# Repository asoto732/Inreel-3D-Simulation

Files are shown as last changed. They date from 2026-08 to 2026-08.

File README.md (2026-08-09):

# InReel Deflection System — 3D Model / CAD

Mechanical CAD for the deflection (gimbal) system on Sandvik's electrified rotary drill rigs. Companion repo to the firmware/control-logic repo (`Sandvik-Common/dri`), split out because CAD assets (STEP/STL exports) don't belong version-controlled alongside code.

## Scope

Two-axis gimbal that measures cable angle deviation and feeds the cable reel control loop. This repo covers the mechanical yoke/mounting design; encoder signal processing and control logic live in `dri`.

## Current encoder — TURCK QR24

| Parameter | Value |
|---|---|
| Model | RI360P0-QR24M0-CNX4-2H1150 (TURCK ID 1590914) |
| Measuring principle | Contactless, inductive (RLC coupling) |
| Shaft diameter | **12 mm** — encoder mounts directly, no stub/adapter needed |
| Air gap | Sensor head and positioning element are separate; nominal **1.5 mm** gap between them |
| Mounting | Hollow shaft 6–20 mm; separate P-series positioning element (per axis) + aluminum ring; mounting aid MT-QR24, closure cap VZ 3 |
| Sealing | IP68 / IP69K |

Full datasheet: `edb_1590914_eng_us.pdf` (see `dri` repo's `CLAUDE.md` for the reference table).

## Real yoke/frame CAD (added 2026-07-23)

`cad/` holds the real, externally-authored gimbal parts (not generated by anything in this repo) — a proper 2-axis design:

| File | Part | Native size (in) |
|---|---|---|
| `mounting_frame.stl` | Base frame, bolts to the rig, carries the axis-0 bearing bosses | 17.3 × 21.4 × 20.8 |
| `outer_yoke.stl` | Rectangular yoke ring — bosses on one side pair bolt to the frame (axis-0), the perpendicular pair carries the inner yoke (axis-1). **Replaced 2026-08-09** — see below. | 16.5 × 20.9 × 3.8 |
| `inner_yoke.stl` | Tube holding the encoder/cable passthrough, with two stub pivot shafts for the outer yoke's axis-1 bosses. **Replaced 2026-08-09** — see below. | 15.9 × 6.1 × 12.0 |

These are wired into `docs/gimbal_axis_simulator.html` (loaded live via `STLLoader`, not embedded — at ~1.8–4.7MB each, base64-embedding like the encoder experiment would have bloated the HTML past being readable/diffable, so the simulator now needs to be served rather than double-clicked; see below). The procedural placeholder frame/rings remain as a fallback if a load fails.

**Pivot alignment (axis-0, frame ↔ outer yoke): confirmed with exact CAD coordinates**, not mesh-forensics estimates. An early mesh-proximity heuristic found frame "already touching" outer_yoke in the raw STL export and assumed that meant they shared a coordinate system — that assumption was wrong (a direct proximity check later showed frame was actually closer, in the raw export, to a *different* boss pair than the one that's really meant to mate, confirmed against reference photos). The user then read exact hole/pin center coordinates directly from the CAD tool:

| Feature | Native coordinates (in) |
|---|---|
| Outer yoke, left shaft-hole | (7.1061, -2.2958, 1.5000) |
| Outer yoke, right shaft-hole | (7.1061, 17.1822, 1.5000) |
| Frame, left leg-hole | (3.3266, -5.7665, -14.1875) |
| Frame, right leg-hole | (3.3266, 13.2085, -14.1875) |

Both pairs run along native Y (consistent axis direction, good sign the parts are meant to mate here). `FRAME_NATIVE_OFFSET` in `transformYokeGeometry()` translates frame's leg-hole axis onto outer yoke's shaft-hole axis exactly on the two perpendicular axes; the third (axial) direction has the two pairs' hole-spacing differing by ~0.5in, so a single rigid transform can't satisfy both endpoints exactly — the residual (~6.4mm) is split evenly between the two ends, verified directly against the transform math (not just the mesh) in-browser.

**Pivot alignment (axis-1, outer yoke ↔ inner yoke): also confirmed with exact CAD coordinates.**

| Feature | Native coordinates (in) |
|---|---|
| Outer yoke, left female pivot hole | (13.1061, 7.4432, 1.5000) |
| Outer yoke, right female pivot hole | (1.1061, 7.4432, 1.5000) |
| Inner yoke, left male stub shaft | (3.0700, -8.1604, 10.7500) |
| Inner yoke, right male stub shaft | (18.4697, -8.1604, 10.7500) |

Both pairs run along native X. Nice cross-check: this pair's midpoint X (7.1061) and fixed Y (7.4432) both match axis-0's numbers exactly, confirming both axes truly intersect at one consistent point, `NATIVE_PIVOT = {x:7.1061, y:7.4432, z:1.5000}` (fully exact now, not an estimate on any axis).

Unlike axis-0, this pair has a much bigger span mismatch: inner yoke's stub-to-stub span is 15.40in, outer yoke's hole-to-hole span is 12.00in — a 3.40in difference. Midpoint-aligning (same method as axis-0) leaves a real **~1.7in (~43mm) residual per end**, confirmed directly against the live transform math via `javascript_tool`, not just the mesh. Checked whether this was a left/right mislabeling (it isn't — neither direct nor crossed point correspondence explains it away) — more likely a shaft's own "center" (a point along its length) isn't the same reference as a hole's center once it's inserted partway. Flagged rather than silently absorbed; if this matters for anything beyond visualization, worth asking whichever coordinates were pulled whether the shaft's *insertion-end* point (rather than its overall midpoint) was intended.

**Frame orientation (up/down flip, then 90° yaw) — visually confirmed correct by the user**, but the yaw fix (`rotateY90`) was later found to be a real bug — see below.

**Which slider drives which rotation.** Briefly swapped (X/Y ↔ innerGroup/outerGroup), then reverted ("the axes are not correct") — the original assignment stands: **Axis 0/X drives `outerGroup`** (frame↔outer_yoke), **Axis 1/Y drives `innerGroup`** (outer_yoke↔inner_yoke).

**Bug found and fixed: `rotateY90` was breaking the frame connection (2026-07-23).** The 90° yaw fix mentioned above swapped simX/simZ *after* the native→sim mapping — which silently moved axis-0 (the frame↔outer_yoke shaft-hole line) off of world Z, the axis `outerGroup` actually rotates about. Verified directly against the live deployed function (not a reimplementation — that's exactly what missed this the first time): with `rotateY90`, axis-0's points came out at `simX≈±0.247` (varying), `simY≈0`, `simZ≈0` — sitting on the **X** axis, not Z. Since frame is static (added to `scene`, never rotates) and outer_yoke's shaft-hole needs to stay coincident with frame's leg-hole as Axis 0 changes, this meant the connection would visibly separate as soon as the X slider moved away from 0 — invisible in a static screenshot, but real.

Fixed with a proper replacement, `axis1Vertical`, instead of patching `rotateY90` further: it leaves native Y → simZ **untouched** (axis-0 stays exactly on Z, unaffected — frame's `rotateY90` was removed entirely, back to its original formula), and re-routes native X (axis-1's varying direction, per the user: *"the inner yoke needs the pivots lined up on the Y axis"*) to simY instead of simX — putting the outer_yoke↔inner_yoke pivot on the **vertical** axis. `innerGroup`'s rotation was changed from local-X to local-Y to match. Both are proper rotations (det=+1 in each case), not mirrors.

Verified against the live deployed function for all 4 relevant points at once: frame's axis-0 lands at world `(0, 0.75, ±0.241)`; outer_yoke's axis-0 lands at local `(0, 0, ±0.247)` (same line, once `outerGroup`'s position is added — connects to frame); outer_yoke's axis-1 lands at local `(0, ±0.152, 0)`; inner_yoke's stub lands at local `(0, ±0.196, 0)` (same line as outer_yoke's axis-1 — connects). The small residuals present (~6.4mm axis-0, ~43mm axis-1) are exactly the previously-disclosed span-mismatch amounts from the exact-coordinate section above, not new errors.

**Facing direction restored with `rotateY180` (not `rotateY90`).** Removing `rotateY90` fixed the connection bug above, but it also removed the yaw correction it had accidentally been providing — the gimbal needed to face away from the rig again. A 90° yaw is exactly what broke axis-0 (it moves the Z-axis onto the X-axis); a **180°** yaw about sim-up does not: `Ry(180)` is `(simX,simY,simZ)→(-simX,simY,-simZ)`, which maps the Z-axis to itself (sign-flipped) and the Y-axis to itself too — both pivot alignments survive it exactly (proper rotation, det=+1). Applied to frame and outer_yoke only (matching each other, as before); verified the same way — all four pivot points land at the same X/Y/Z magnitudes as before `rotateY180`, just with axis-0's Z-values sign-flipped as expected, connections intact.

**Slider assignment re-swapped to match the written requirements doc (2026-07-24).** A formal requirements doc now serves as the authoritative spec, and it states "the inner yoke represents the x-axis of the deflection" / "the outer yoke represents the y-axis". The deployed code contradicted this, so the assignment was swapped (after explicitly confirming, since this same swap had been made and reverted once before): **Axis 0/X drives `innerGroup`**, **Axis 1/Y drives `outerGroup`** — the opposite of the line above, which is now superseded.

**Cable was frozen on the rotation axis (2026-07-24).** The cable/hub/dragHandle all sat at `innerGroup`'s local origin — which, after `axis1Vertical` moved axis-1 to vertical, *is* `innerGroup`'s rotation axis. Rotating about an axis never moves points lying on it, so the X slider visibly did nothing (a pendulum spun along its own string). Fixed by anchoring them at the real tube-exit point read directly off the loaded `inner_yoke` mesh's local bounding box, rather than an arbitrary offset. The drag-to-rotate inverse-kinematics further down assumed the cable hangs from the exact origin, so it's now only an approximation — not re-derived, since the requirements call for slider + tension control, not drag.

**Whole-assembly 90° yaw: `rotateY90` reintroduced, correctly this time (2026-07-24).** The mounting frame's legs needed to run along world X ("legs symmetric with the X axis") instead of along the toward/away-from-rig direction. A top-down render confirmed the real CAD frame is a symmetric rectangular ring whose leg spread *is* the physical pivot shaft line — so the frame can't be rotated alone without breaking the pivot. The fix is a single rigid yaw of the entire already-assembled unit: the same `Ry(90)` (`x'=z, z'=-x`, det=+1, applied post-mapping) is applied **uniformly to all three parts**. This is what the original iteration-3/4 `rotateY90` got wrong — that one was applied to only some parts, leaving them rotationally inconsistent, which is what broke axis-0.

Two dependent values must move in lockstep with the flag, or the connection breaks: `outerGroup`'s rotation axis (world Z → world **X**; `Ry(90)` applied to the old axis vector `(0,0,1)` gives exactly `(1,0,0)`), and the cable/hub/dragHandle offset (local X=+0.273 → local Z=−0.273; same rotation applied to the same point). `innerGroup`'s axis is untouched — Y is the yaw axis itself, invariant under a rotation about Y.

Verified in Python before touching the live JS: the top-down render after the yaw shows every pivot circle still coincident and the legs now spanning X; a numeric swing check confirmed Axis 1 (Y) still drives the cable tip toward more-negative Z (away from rig) as it increases, and Axis 0 (X) still produces pure lateral motion with Y/Z fixed — both matching the documented pre-existing behavior. `scripts/render_combined.py` carries the same `rotate_y90` flag so it stays in sync with the JS.

**Inner yoke stubs swapped to the opposite holes (2026-07-24).** `flip180Z` turned off on `inner_yoke`, so each male stub now mates into the *other* female hole. Verified against the exact CAD coordinates before changing: relative to the pivot, the female holes sit at ±0.1524 and the male stubs at ±0.1956 — with the flip on, `stub_L` sat on the same side as `hole_L`; with it off, `stub_L` lands at −0.1956, mating into `hole_R`. Nothing else moves (the mesh's local X and Z bbox ranges are identical either way, so the cable/hub/dragHandle stay aligned with the real tube end); only Y changes, which *is* the swap.

**Outer ring rotated onto the Y-axis: `rotateX90` (2026-07-24).** The outer yoke ring stood vertical, with the Y-axis (toward/away-from-rig) punching perpendicularly through it. Requested change: the ring's plane should *contain* that axis at zero deflection. Since a ring's plane contains both of its own pivot axes, this is a 90° rotation about axis-0 (world X) — the plane goes from X-up to X-Z, axis-0 stays exactly on X (frame connection untouched, and the frame must **not** get this flag), and axis-1 swings from vertical onto world Z. `Rx(-90)` (`y'=z, z'=-y`, det=+1) is used rather than `Rx(+90)` because it leaves the inner yoke's cable tube pointing **down** instead of up, so the cable still hangs below the gimbal.

Two dependent values move with it: `innerGroup`'s rotation axis (local Y → local **Z**, following axis-1), and the cable/hub/dragHandle anchor (local Z=−0.273 → local Y=−0.273, following the tube end — confirmed against the loaded mesh's bbox, where Y now reaches −0.2731, exactly the value Z used to reach). `outerGroup` stays on world X, since `rotateX90` is a rotation *about* that axis.

Verified before touching the live JS: both pivot axes still land on a single shared line (axis-0 at X=±0.241/±0.2474, axis-1 at Z=±0.1524/±0.1956 — the same two previously-disclosed residuals, no new error), and **both sliders were confirmed to still move the cable**, which is the specific failure mode that bit this file once already. Y swings the tip toward −Z (away from rig), X swings it toward +X (right = positive, per the requirements doc), and they compose correctly.

**Outer yoke turned right-side up: `rotateZ180` (2026-07-24).** With the ring horizontal, the model itself read upside down. Turning it over is a 180° rotation, and two of them do it — but they are **not** interchangeable here. `Rx(180)` (negates simY, simZ) would move axis-1's female holes from Z=−0.1524/+0.1524 to +0.1524/−0.1524, silently undoing the stub-to-hole pairing set by `flip180Z: false`. `Rz(180)` (negates simX, simY) leaves those holes exactly where they are — they sit at simX=simY=0, precisely the components it negates — and only mirrors axis-0's shafts along their own shared line. `Rz(180)` is therefore the correct choice; det=+1, applied last in sim space about the part's local origin. Verified after the change: axis-0 shafts still at X=±0.2474, axis-1 holes still at Z=∓0.1524 with the crossed pairing intact, the ring's Y range flipped, and Z unchanged so front/back orientation is preserved.

> Gotcha for `scripts/render_combined.py`: `world_y` must be **0** for the outer/inner yoke, matching the live JS, where those parts are children of `outerGroup`/`innerGroup` and take their height from `outerGroup.position.y`. Baking `PIVOT_Y` in before `rotate_x90` lets that rotation drag the height into Z. This was harmless for `rotate_y90` (which leaves Y alone) but is not for `rotate_x90` — add the height *after* the transform.

## inner_yoke.stl replaced with Concept 2 (2026-08-09)

`cad/inner_yoke.stl` is now `BG02375111_A_1-Gimbal Inner Yoke Concept 2` — a different design from the part described in the pivot-alignment section above, on its own native coordinate frame unrelated to those numbers (kept above for history; they describe geometry no longer in this repo). Old size 16.8 × 8.0 × 12.0in; new part is 15.9 × 6.1 × 12.0in (same tube height, narrower footprint).

**Unlike every other part in this file, no exact CAD coordinates were available for the new geometry** — the pivot alignment below is a **mesh-derived estimate**, not a CAD-tool readout. Method: binary-parsed the STL directly (struct/numpy, no CAD software involved) and least-squares circle-fit the two stub shafts' cross-sections. The shaft *axis* (Y=2.765in, Z=11.09in) is well-supported — both stubs agree to within 0.01in, and it independently cross-checks against the tube's own hollow bottom-face centroid (X=3.551in, matching the stub midpoint X=3.55in almost exactly). The stub-to-stub *span* is genuinely ambiguous, the same failure mode flagged for the old part above: the shaft is stepped (tip flange, mid-shaft shoulder, a relief groove at the tube wall), and the mesh doesn't say which diameter step is the intended mating reference. Two candidate feature-pairs gave 10.0in and 13.9in spans (target, from outer_yoke's unchanged holes: 12.00in); both agree on the midpoint (X=3.55in), which is what actually sets `INNER_YOKE_NATIVE_OFFSET.x` — so the span ambiguity affects the size of the visual gap at each stub tip, not the part's overall placement.

Rendered and visually checked (`scripts/render_combined.py`, then live in the browser) before shipping: the new part sits centered, right-side-up, and correctly connected to the pivot inside outer_yoke's ring, with a visible per-side gap smaller than the old part's documented 43mm residual. Both sliders confirmed to still move it. `flip180Z` was left at its old default (`false`) — the old part's reasoning for that choice was specific to its own exact coordinates and doesn't carry over, so this is an unverified starting guess, not a confirmed one; if the live sim shows the part mirrored, flip it.

**Open item:** ask whoever has the source CAD tool for this part's exact stub-center coordinates (same ask that was answered for the frame/outer_yoke/old inner_yoke) to replace this estimate with a real one.

## outer_yoke.stl also replaced with Concept 2 (2026-08-09)

`cad/outer_yoke.stl` is now `BG02375110_A_1-Gimbal Outer Yoke Concept 2`. More consequential than the inner_yoke swap above: `NATIVE_PIVOT` has always been outer_yoke's own native coordinates — every other part's offset is measured relative to it — so this replacement means re-deriving the shared pivot itself, not just adding an offset. Old size 17.0 × 20.9 × 4.1in; new part is 16.5 × 20.9 × 3.8in (same Y span, close overall scale).

Same mesh-only method as inner_yoke, no exact CAD coordinates available for this part either. Circle-fit axis-0's stub shaft at its two Y-extremes (top/bottom, matching the old top/bottom-stub convention): X=7.946in, Z=1.486in and Z=1.500in — tight agreement. Circle-fit axis-1's feature at its two X-extremes (left/right): Y=6.563in/Z=1.511in (left) and Y=6.607in/Z=1.496in (right) — also tight. Axis-0 and axis-1 independently landed near Z=1.50in, matching the *old* outer_yoke's own Z=1.5000in exactly — reads like a real shared datum plane on this assembly, not a coincidence. Used `NATIVE_PIVOT = {7.946, 6.585, 1.500}` (the four estimates above, averaged, with Z rounded to the value they all bracket).

**Open question, not resolved:** axis-1 is asymmetric on this part in a way the old outer_yoke wasn't. The left end is a confirmed-hollow bore (0 vertices at the fitted center — a real hole). The right end is a gear-toothed boss with a confirmed-**solid** pin/tab at its center (real vertices right at the fitted center, plus a separate tab feature at the same Y) — a male feature, not a hole. The new inner_yoke has male stubs on *both* ends, so the left side mates fine (stub into bore), but the right side would be male-pin-meets-male-stub, which isn't a valid mechanical mate as modeled. Possibilities: the right "pin" isn't the axis-1 mate at all (an encoder shaft stub, a lock feature — the real hardware's QR24 encoder does have a separate sensor/positioning-element pair, which this might be echoing), or a cover/bracket not in this repo is meant to go there. Averaging both ends' Y/Z for `NATIVE_PIVOT` sidesteps the question for visualization purposes only — both ends are close enough together (within 0.05in) that the render looks correctly connected either way — it does not answer what the right-side pin is actually for.

Rendered and visually checked (`scripts/render_combined.py`, then live in the browser) before shipping: sits centered, right-side-up, connected to both the frame (axis-0) and the new inner_yoke (axis-1). Both sliders confirmed to still move the full assembly through a wide range (checked at X=−45°, Y=−90°) without anything visually detaching. The existing rotation flag set (`rotateY180`, `rotateY90`, `rotateX90`, `rotateZ180`) was kept unchanged and re-verified empirically against the new mesh, rather than re-derived analytically — the written rationale further up this file for *why* those specific flags are correct still refers to the old part's exact numbers.

**Open item:** same as inner_yoke — ask whoever has the source CAD tool for this part's exact axis-0/axis-1 coordinates, and in particular what the right-side pin feature is, to replace this estimate and resolve the mating question above.

## Duty cycle override, and a 5 HP hydraulic motor test case (2026-07-27)

Two additions to the torque check panel above.

**"Test a specific duty cycle instead of the live one"** decouples the torque box from the sliders. Off (default), it reads whatever duty the reel-trim loop is actually producing, every frame. On, a 0–100% slider substitutes a manually chosen value instead, so you can ask "what would 50% duty do" without driving the encoders to whatever angle happens to produce it. Verified live: with the override at 40% and the sliders driven to a position that genuinely produces 12% duty in the real reel-trim loop, the torque box correctly held at 40% every frame, ignoring the live value entirely.

**"Load 5 HP hydraulic motor (illustrative)"** fills in a torque figure for a hydraulic motor rather than the electric-motor framing the panel started with. This matters for two real reasons, not just as another preset:

- Power alone doesn't give torque — converting needs a speed (`torque = power / ω`). No real hydraulic motor spec exists in this repo either, so the preset assumes an illustrative 500 RPM rated speed to get there: 5 HP = 3728.5 W, at 500 RPM (ω = 52.36 rad/s) → **~71.2 Nm**. That 500 RPM is flagged in the code and the UI as an assumption, not a datasheet number, same discipline as everywhere else values are estimated in this project.
- **Hydraulic motors don't have back-EMF.** The whole "torque tapers to zero at no-load speed" caveat from the earlier DC-motor discussion doesn't apply here — a hydraulic motor's torque stays roughly flat across its speed range, set mostly by system pressure rather than by a voltage/back-EMF balance. The `duty% × torque × ratio × efficiency` formula is still reused as a first-pass approximation, but its correctness now depends on a different, unconfirmed assumption: whether the real `DO_Motor_Wind`/`DO_Motor_Unwind` outputs actually drive the hydraulics through a time-proportioned valve (where duty ≈ average flow ≈ average torque, a reasonable approximation) or through something else entirely.

Verified: `HYDRAULIC_5HP_TORQUE_NM` computes to 71.209 Nm in the browser, matching the hand calculation exactly. At 75% test duty, default (electric) placeholder spec gives 956.25 Nm; loading the hydraulic preset at the same 75% gives 192.24 Nm — both match `duty × stall × ratio × eff` exactly, confirming the preset and the override compose correctly together.

## Motor & drum torque check (2026-07-27)

Follow-on to the tuning panel above. Fixing the scale and contribution factor means the reel *reports* a duty cycle at realistic deflection angles — but duty cycle isn't torque, and nothing in either repo confirms that duty actually moves the real drum. This panel makes that gap explicit rather than assuming it away.

**What's real:** drum inertia `I(L)`, ported directly from `scripts/reel_inertia_model.py` (the closed-form continuous-annulus approximation — cross-checked there against the discrete layer method to <0.1%). Same real geometry (62in core, 72.25in width, 72in flange) and real cable spec (Nexans 36-517-002). Verified the JS port against the Python reference values at three points (empty, half, full spool) — **0.000% difference** at all three; the constants are copied from a script run, not hand re-derived, so they won't drift.

**What's a placeholder:** motor stall torque, gear ratio, and drivetrain efficiency. No motor spec exists in either repo. Defaults are round illustrative numbers (50 Nm / 30:1 / 0.85), and the panel displays an explicit warning whenever those defaults are still in place, so the numbers can't be mistaken for real ones.

**The model:** a stall-torque approximation — `torque available = duty% × stall torque × gear ratio × efficiency` — deliberately simple (no back-EMF correction), since the question being asked is "can it start moving at all," not "what's its running speed." `angular acceleration = torque / I(L)`.

Example, at the defaults: 12% duty (X axis at its ±45° mechanical limit, default 0.12 contribution factor) against a half-wound drum (I ≈ 1771 kg·m²) gives 153 Nm available and 0.086 rad/s² (~0.8 RPM/s) — a real number now, but only as good as the placeholder motor spec feeding it. **This box does not say whether 12% duty is enough — it can't, until real motor numbers replace the placeholders.** That's the actual open question for the team, not something this sim can resolve on its own.

## P-control tuning panel, and why the reel never responded (2026-07-27)

The reel indicator was showing HOLD at every realistic deflection angle. The LEDs were fine — there was genuinely nothing to show. Two compounding problems:

**1. Scale mismatch.** `raw01perc` is `signedCounts * 1000 / 32768`, and 32768 counts is **180°** of encoder travel. So the ±1000 per-mille vector is calibrated for a half turn. The gimbal is mechanically hard-stopped at **±45°**, so the real mechanism only ever exercises the bottom quarter of that scale. At its 45° limit an axis reaches 250 of a possible 1000 per-mille; the rescale turns that into ~167, and the contribution into ~0.020 — five times under the 0.10 discard threshold. **No deadzone value fixes this**; raising the deadzone only shrinks the result further.

This also means the config numbers don't mean what people assume. At the 180° scale, the X deadzone of ±100 is **±18°**, and Y's ±350 is **±63°**.

**2. No headroom.** Contribution is `vector/1000 × 0.12`, tested against a 0.10 discard threshold — so output only exists above vector 833, the **top 17%** of the range, even once the scale is right.

Measured, via the panel's solver:

| Config | X axis | Y axis |
|---|---|---|
| Today's firmware (180°, 0.12) | needs 153° — **never responds at all** | from 160.5° (top 11%) |
| Scale fixed (45°, 0.12) | from 38.3° (top 15%) | from 40.1° (top 11%) |
| Scale + factor (45°, 0.5) | from 12.6° (**top 72%**) | from 21.6° (top 52%) |

**The panel** exposes full-scale deflection, both contribution factors, and the discard threshold as live controls, with a solver reporting the smallest angle on each axis that actually produces a reel command. Every deadzone field is now labelled with its equivalent in degrees at the current scale — the unlabelled per-mille is what made this hard to see.

`computeAxis()` takes `fullScaleDeg`, defaulting to 180 so **passing 180 reproduces the firmware exactly**. The UI defaults to 45 (the real mechanical travel) so the sim is useful out of the box; "Reset to today's firmware" restores 180 / 0.12 / 0.10 for side-by-side comparison. `raw01perc` is now clamped to ±1000, since nothing stops an axis being driven past its full-scale reference and an unclamped vector would break the per-mille contract.

Verified live at 45° scale with 0.5 factors: X=30° → vector 629, contribution 0.315, 31% duty, UNREEL. Y=−30° → vector −486, contribution −0.243, 24% duty, REEL IN. Rest → HOLD. All three states reachable at angles the gimbal can physically reach.

> None of this is changed in firmware — it's a simulator instrument for deciding what the config *should* be. The scale question in particular needs a decision before it goes near `cablereel_signals.xml`.

## Reel command indicator (2026-07-24)

The reel trim panel shows a three-state command — **UNREEL / REEL IN / HOLD** — mirroring the firmware's two real digital outputs, `DO_Motor_Unwind` and `DO_Motor_Wind` (`cablereel_signals.xml`). HOLD is not its own signal: it's the implicit state when both outputs are low, exactly as the hardware behaves, so it's derived rather than invented.

The active states **flash at the real PWM period** (1000 ms, `Deflection_Trim_PWMPeriod_ms`) with on-time equal to the duty cycle. That's not decoration — the reel motor has no analog speed input, so these digital outputs genuinely are pulsed at that period, and the duty cycle *is* how reel speed is modulated. A low duty visibly blinks briefly; 100% sits solid. Verified: at 12% duty the indicator measured lit on 0.17 of samples; at rest it is steady on.

**Reaching a non-HOLD state takes more than moving a slider.** Three gates in series: the published vector must clear its deadzone (X past 18°, Y past 63°), then the EMA-smoothed contribution must ramp up, then it must exceed the 0.10 discard threshold. Measured thresholds:

| State | Condition | Notes |
|---|---|---|
| UNREEL | Y ≳ 64°, or X ≳ 19° | X is absolute, so either direction only pays out |
| REEL IN | Y ≲ −165° | narrow window — see below |
| HOLD | everything else | |

REEL IN is only reachable in roughly a 15° window (−165° to −179°). At −160° the contribution is −0.0994, just under the 0.10 discard threshold; and −180° wraps to exactly +180° (same absolute encoder position), reading +1000. This narrowness is a real consequence of the config, not a sim artifact — worth raising alongside the ±350 Y deadzone question.

**Bug fixed alongside this:** the slider listeners were bound as `addEventListener('input', render)`, capturing the original `render` by reference. `render` is reassigned further down to a wrapper that also refreshes `currentVX`/`currentVY` — the values the reel-trim loop reads — so slider moves only ever called the unwrapped version and those stayed 0. Now bound as `() => render()`, which defers the lookup to call time.

> Testing note: `requestAnimationFrame` is paused in a non-fronted browser tab, which halts `stepReelTrim` entirely and freezes every value it writes. When verifying this panel through automation, front the tab first (`tabs_select`) — otherwise a dead loop looks exactly like a logic bug.

Encoder mount points inside the inner yoke, and the P-series positioning-element bracket details, still aren't modeled — see the QR24 section below for what's real vs. placeholder there.

## Structure

- `step/` — STEP exports (neutral exchange format, authoritative geometry) — from `generate_model.py`, placeholder shapes
- `stl/` — STL exports (for viewing/printing/reference) — from `generate_model.py`, placeholder shapes
- `cad/` — real, externally-authored STL parts (frame, outer yoke, inner yoke) — see above
- `docs/` — supporting notes, datasheets, reference images, and `gimbal_axis_simulator.html`
- `scripts/generate_model.py` — parametric CadQuery script that builds the placeholder assembly below (`py -3 scripts/generate_model.py`, needs `pip install -r requirements.txt`)
- `scripts/reel_inertia_model.py` — cable reel moment-of-inertia model, as a function of spooled cable length (`py -3 scripts/reel_inertia_model.py`). See "Reel inertia model" below.
- `scripts/find_bosses.py`, `scripts/render_combined.py` — derivation/verification tools for the real yoke CAD's pivot alignment (see above)
- `renders/` — matplotlib sanity-check renders (STL screenshots, the inertia-vs-length plot, the combined yoke check)

## Running the simulator

`docs/gimbal_axis_simulator.html` now fetches the real yoke STLs at runtime, so it needs to be served rather than opened directly (`file://` blocks the fetch via CORS in most browsers):

```
py -3 -m http.server 8000
```
...run from the repo root (`inreel-cad/`, not `docs/`), then open `http://localhost:8000/docs/gimbal_axis_simulator.html`.

## Placeholder CAD (generate_model.py output)

Generated with basic shapes (boxes, cylinders, annuli) — a placeholder used to visualize the assembly and unblock downstream work before the real yoke CAD above existed. Superseded for the frame/outer/inner-yoke geometry, but the encoder pair below is still the best available QR24 model.

- **`qr24_encoder_pair.step` / `.stl`** — dimensionally accurate to `docs/edb_1590914_eng_us.pdf` (TURCK datasheet): Ø77×24mm sensor housing, Ø22mm bore, 3× Ø4.3mm mounting holes on a 65mm bolt circle, M12 connector boss, plus the P3-RI-QR24 positioning element (12mm bore) held at the datasheet's **1.5mm nominal air gap**. The positioning-element outer geometry (52mm OD, 42mm bolt PCD) is *not* datasheet-dimensioned — it's sized against the sensor's own bolt circle and the SP3-QR24 shield plate's stated 52mm OD, so treat those two numbers as placeholders pending the accessory's own drawing.
- **`gimbal_assembly.step` / `.stl`** — full scene: frame, rig marker, outer/inner ring, cable, reel barrel, and one encoder pair per axis at illustrative mount points, at 1 sim unit = 1 meter. Not updated to the real yoke geometry yet — only the HTML simulator has been.

**Not yet modeled anywhere:** encoder mounting inside the inner yoke tube; mechanical hard stops as physical geometry (they exist as a software clamp in the simulator, ±45° on axis-0); cable routing/pulley.

## Reel inertia model

`scripts/reel_inertia_model.py` computes the cable reel's moment of inertia **as a function of spooled cable length**, `I(L)` — inertia (and required motor torque) changes continuously as cable winds on/off and the wound radius grows/shrinks, so a single static number isn't enough for control tuning.

Extends the TU Delft Design Report's sum-of-hollow-cylinders method (`I = ½m(r₁²+r₂²)` per component: collector + flange + drum + wound cable), which produced a single static I=0.032 kg·m² for their small 12V prototype motor and demo cable — that number doesn't transfer to the real Sandvik rig (different cable, different drum, different motor), so this model uses the real drum geometry and real Nexans cable spec instead:

| Input | Value | Source |
|---|---|---|
| Cable | 36-517-002 (2 AWG SHD-GC), 4.21 kg/m, 53.8mm OD | Nexans AmerCable Tiger Brand 36-517 datasheet |
| Drum core diameter | 62 in (Ø1.575 m) | Real Sandvik reel spec |
| Drum width | 72.25 in (1.835 m) | Real Sandvik reel spec |
| Flange diameter | 72 in (Ø1.829 m) | Real Sandvik reel spec |
| Core/flange mass | Estimated (steel, 25mm wall, 7850 kg/m³) | **Not spec'd yet** — replace with real weights if available |

Two independent methods are computed and cross-checked (agree to ~0.03% at the real geometry): a discrete layer-by-layer sum (primary, physically accurate) and a closed-form continuous-annulus approximation (fast sanity check). `max_cable_length()` is derived from the real geometry + cable OD rather than needing a separate capacity spec — comes out to ~359m for this cable/drum.

**Not yet available:** motor/gearbox ratio + rotor inertia, needed to reflect `I(L)` through to the motor shaft (`I/N² + I_motor_rotor`) for actual torque/control-tuning work — the function signature leaves room for it once that spec exists.

## Origin

TU Delft Robotics Minor (Jan 2026 handover) → Sandvik Phase 2 production integration. Contact: inreel.cs@gmail.com

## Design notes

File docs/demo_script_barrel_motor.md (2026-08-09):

# Demo script — barrel & motor physics update

Covers commit `b2ca5ad` on `reel-command-indicator`: real Sandvik motor spec,
real torque-driven drum dynamics, and a cable capacity interlock. Verified
live against the running sim before writing this, not just read off the diff.

Where to look: scroll to the bottom of the right-hand column in
`docs/gimbal_axis_simulator.html` — three stacked panels, in this order:
**Cable capacity interlock** (green border) → **Motor & drum torque check**
(red border) → the reel command indicator above them.

---

## 1. The drum used to fake it — now it doesn't

**Say:** "Before this change, the barrel spinning in the 3D view was
cosmetic — it spun at a rate proportional to duty cycle, full stop. Now it's
a real equation of motion: `I(L) × dω/dt = net torque`, integrated every
frame using actual elapsed time."

**Show:** Drive the Y (directional) slider toward its max, watch the
**"Drum speed"** and **"Drum inertia I(L)"** readouts in the torque check
panel update live, and watch the barrel's spin rate visibly lag behind the
duty change rather than snapping to it.

**The concrete result of this:** a heavily spooled drum (high inertia)
accelerates more sluggishly than a nearly-empty one at the same commanded
duty — that lag simply didn't exist in the old model. It also means the
drum can now **fail to move at all** if available torque can't overcome the
load — a real, demonstrable failure mode, not something clamped away.

---

## 2. The motor spec is now real, not illustrative

**Say:** "Every torque number up to this point was a round placeholder —
50 Nm, 30:1 gear ratio, made up so the mechanism was visible. That's gone.
This is now sourced from a real Sandvik vendor hydraulic calc sheet."

**Show:** Click **"Load Sandvik reel motor (theoretical, from vendor calc
sheet)"** in the torque check panel.

**The numbers, and why they're trustworthy — verified live, not just quoted
from a comment:**

| Value | Number | Where it comes from |
|---|---|---|
| Motor torque | **432.4 Nm** | pressure (1000 PSI) × displacement (393.9 cc) / 2π — matches the vendor sheet's own 432.4 Nm |
| Gear ratio | **1.4545** (32:22) | real sprocket-chain reduction on the rig — a **20× correction** from the old 30:1 placeholder |
| Efficiency | **1.0** | the theoretical column assumes an ideal, lossless chain — confirmed exactly: 432.4 × 32/22 = **628.9 Nm**, matching the sheet's peak reel torque to the decimal |
| Peak reel speed | **13.9 RPM** | flow-limited cap from the sheet, used as the drum's hard speed ceiling |

**One number that's worth saying out loud in the room:** the sheet also has
a real *Eaton catalog spec* column that runs *higher* than the theoretical
one (520 Nm / 15.0 RPM / 756.4 Nm at the reel) — because a catalog rating
already includes real motor losses an ideal calc doesn't capture. The
theoretical column was chosen deliberately as the **more conservative**
default, not because it's the only real number available.

**One open item, say it plainly if asked:** the calc sheet's own cable
diameter (2.2 in) doesn't quite match the Nexans spec the drum model uses
(2.12 in) — about 4% off, not rounding noise. Flagged, not silently
reconciled. Worth asking whoever owns that sheet which one is authoritative.

---

## 3. Why unwind couldn't move at all — and the fix

This is the most concrete "we found a real bug via physics, not
guesswork" moment in the whole update, worth telling as a story rather than
just stating the fix.

**Say:** "When we first wired the real motor spec into the real inertia
model, unwind stopped working entirely — the drum simply wouldn't move in
that direction, at any duty. That wasn't a UI bug, it was the physics
telling us something true: the real Sandvik motor (629 Nm at the drum)
literally cannot out-pull the real 200 lbf vendor-recommended cable tension
(725–772 Nm at this drum's radius) if you model tension as a symmetric
resistive force in both directions."

**The fix, and why it's not a fudge:** cable tension isn't friction — it
doesn't flip sign to oppose whatever the drum happens to be doing. It has a
**fixed physical direction**, toward unwind, because it's the rig pulling
cable off the reel. So:

- **REEL IN** — tension genuinely opposes the motor. If tension ever wins,
  the drum gets dragged into unwinding *despite* the wind command — a real
  failure mode this sim now shows rather than clamps away.
- **UNREEL** — tension now *assists* the commanded torque, because that's
  physically what's happening: the rig is pulling cable out, the motor is
  mostly just controlling the release rate, not fighting the load.
- **HOLD** — unchanged: a stationary, uncommanded drum is still treated as
  fully held (no counterbalance/holding-valve spec exists to model creep,
  flagged as an open item, not invented).

**Show:** drive the Y slider to make the reel unwind, and point out it now
actually moves — that literally didn't work before this fix.

---

## 4. The cable capacity interlock

**Say:** "This started as a question during an LLM council review: should
we add a drum encoder so the rig knows how much cable is left before it
tries to tram away? The council flagged a specific, subtle danger in how
you'd naively build that — turns × circumference isn't a valid way to
convert 'turns of the drum' into 'meters of cable,' because each layer
winds at a larger radius than the one before it. The naive math drifts
worst exactly where an interlock threshold lives — near empty."

**Show:** point at the **Turns remaining**, **Layer**, and **Spooled
length** readouts, and the capacity bar underneath them.

**The verified numbers:** this drum holds cable across exactly **2
layers**, **68 turns** total (34 wraps per layer — width ÷ cable OD), and
the layer-by-layer model reconciles to **359.40 m** — matching the drum's
known real capacity (359.4 m) to within a tenth of a meter. That
reconciliation check is deliberate: confirm the model agrees with known
reality before trusting it for anything downstream.

**Also worth mentioning:** during the council review, one advisor estimated
roughly 8–9 layers by eyeballing it; another (correctly) estimated around 2
by working from the flange/core radius gap. The exact model settled it —
worth saying, since it's a good example of why you build the real model
instead of trusting either guess.

**The TRAM ALLOWED / TRAM BLOCKED indicator:**

- Two independent thresholds — **warn** and **block** — not one, so there's
  a visible "getting close" state before an actual lockout.
- **Hysteresis via a rearm margin**: once blocked, capacity has to climb
  back *above* block+margin before it clears — a single hard threshold
  chatters right at the boundary, which is exactly the kind of nuisance
  lockout that gets routed around by operators in the field. This was also
  a specific council-flagged failure mode.
- **Simulate encoder fault** checkbox: forces BLOCKED regardless of actual
  capacity — fails closed, matching the DS-SF-02 posture already used
  elsewhere in this project for sensor faults.

**Caveat to state plainly:** this box is informational only — the sim has
no actual tramming/drive feature for it to gate. It's a live readout of
what a real interlock built this way *would* report.

---

## Closing line, if you need one

"Everything in this update replaced a placeholder with something either
measured or derived from a real vendor spec, and where the physics
disagreed with an earlier assumption — like the symmetric tension model
that made unwind impossible — the fix came from taking the disagreement
seriously rather than clamping it away. The two open items — the 4% cable
diameter mismatch and the missing holding-valve spec — are named, not
buried."

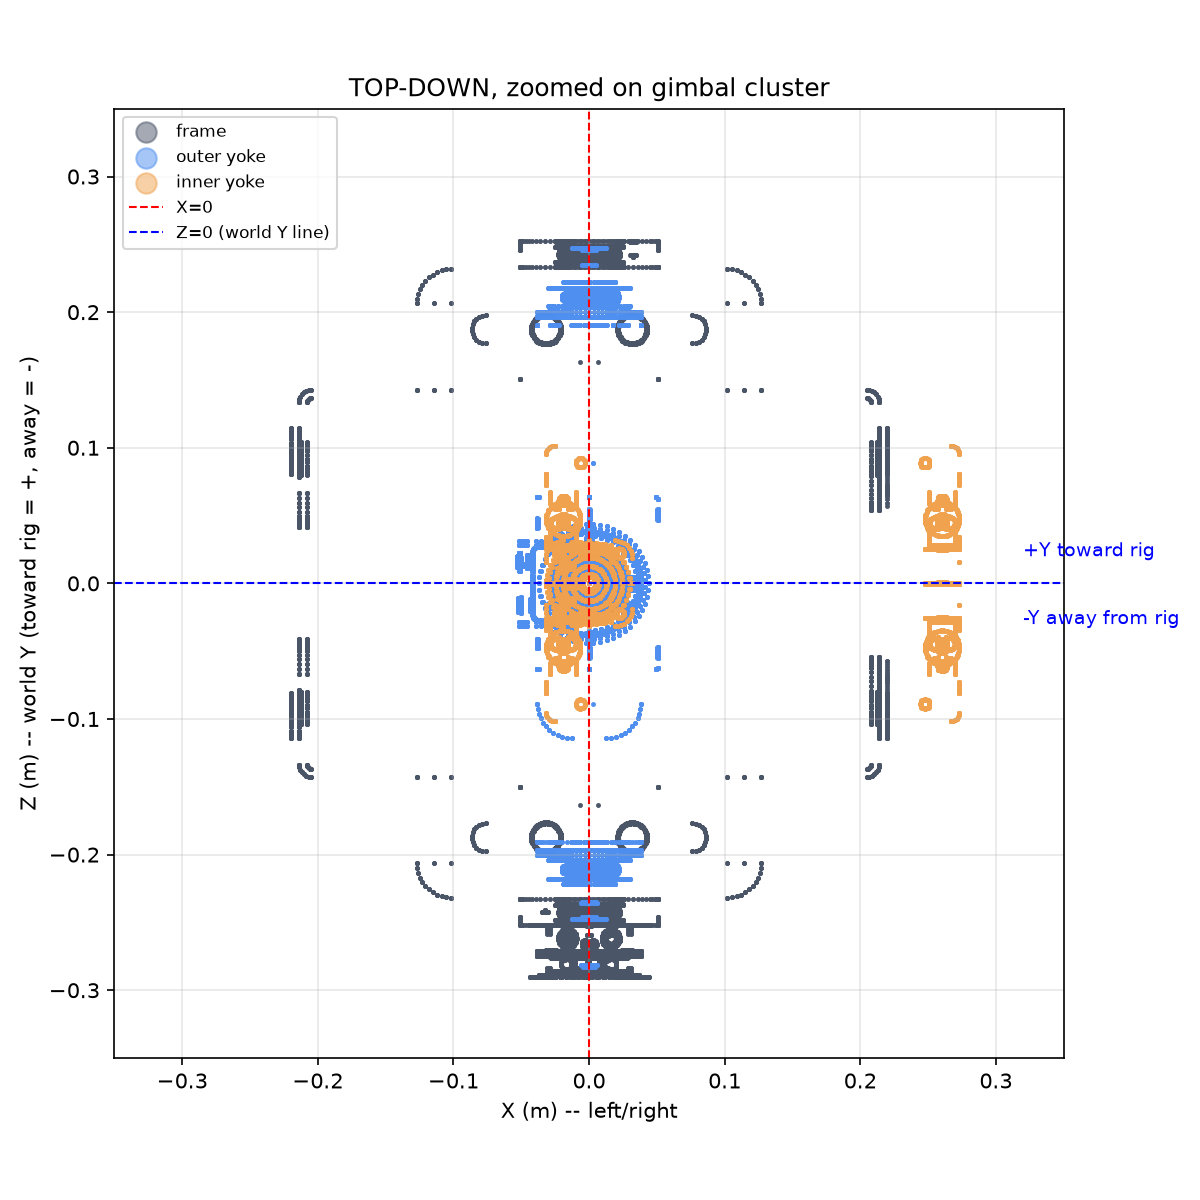
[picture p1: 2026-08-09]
renders/topdown_zoom_check.png

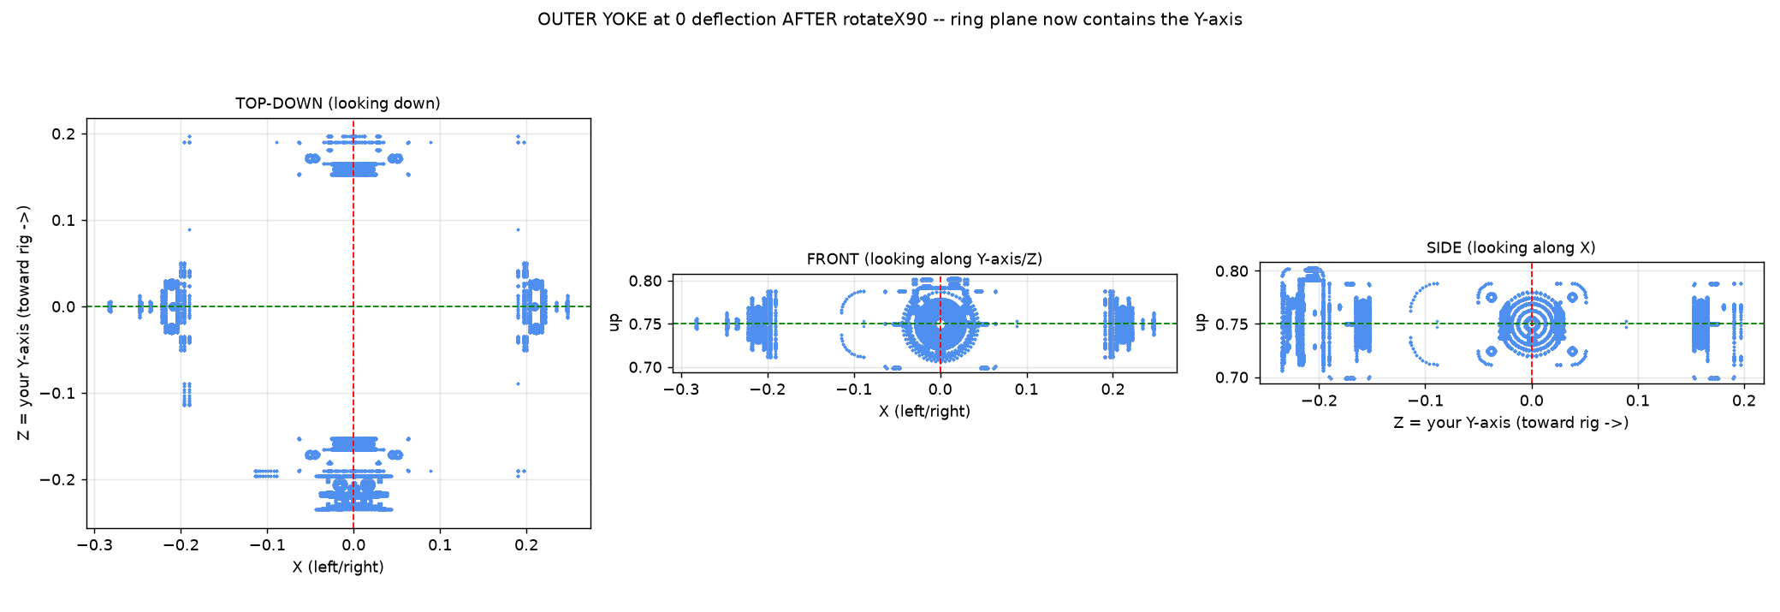
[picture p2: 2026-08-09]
renders/outer_yoke_rest.png

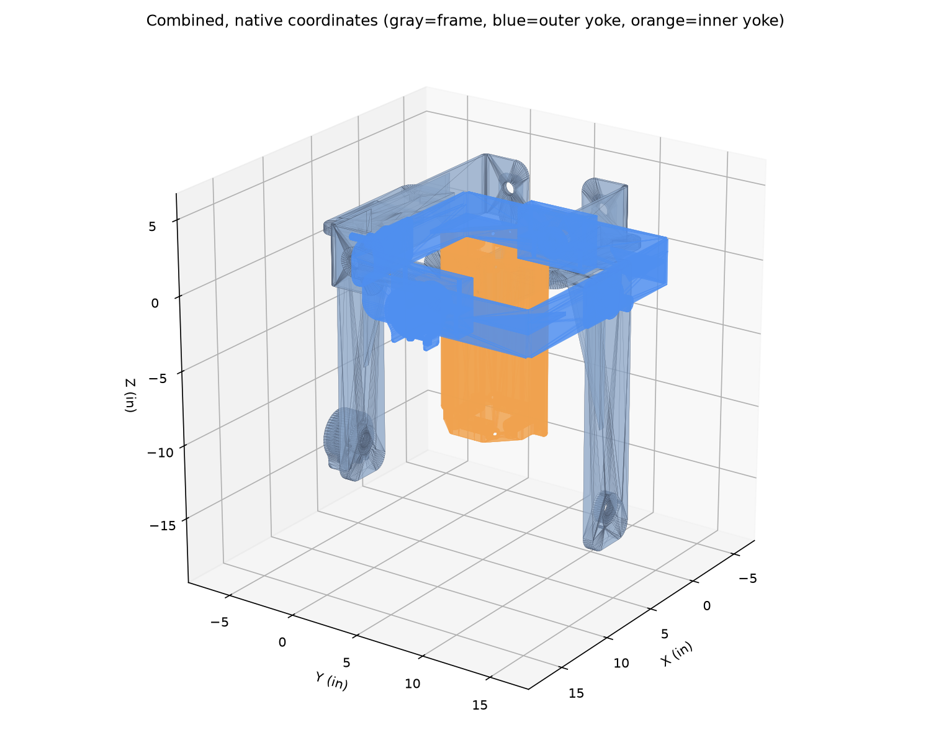
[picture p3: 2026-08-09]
renders/real_combined_native.png

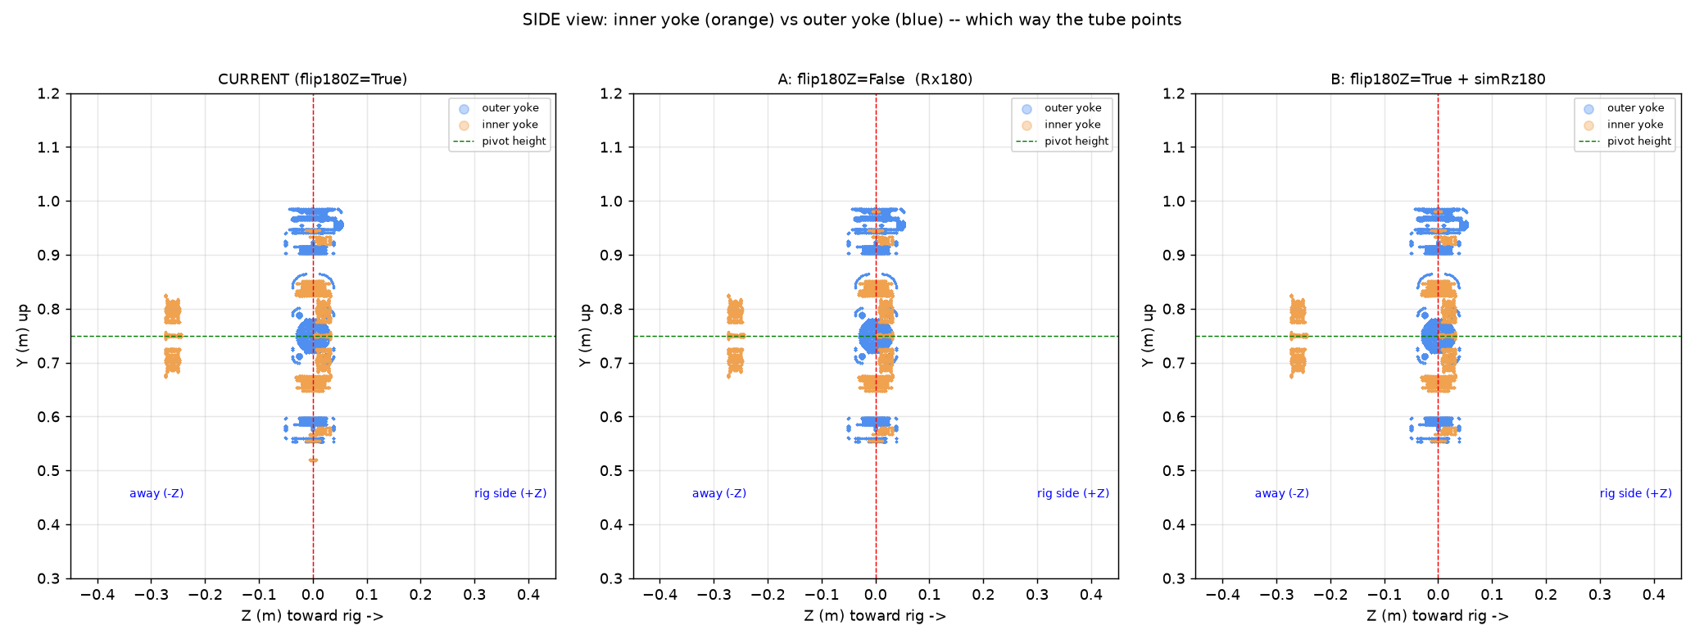
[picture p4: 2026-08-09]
renders/inner_flip_options.png

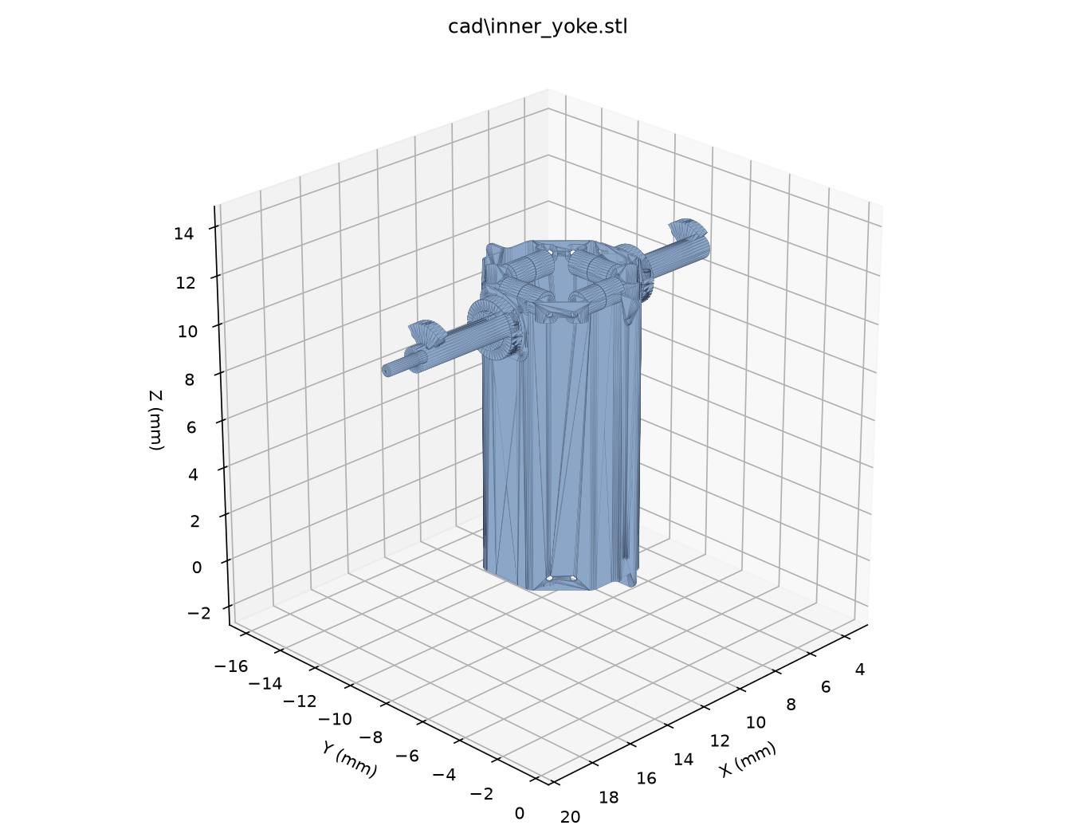
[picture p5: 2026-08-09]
renders/real_inner_yoke.png

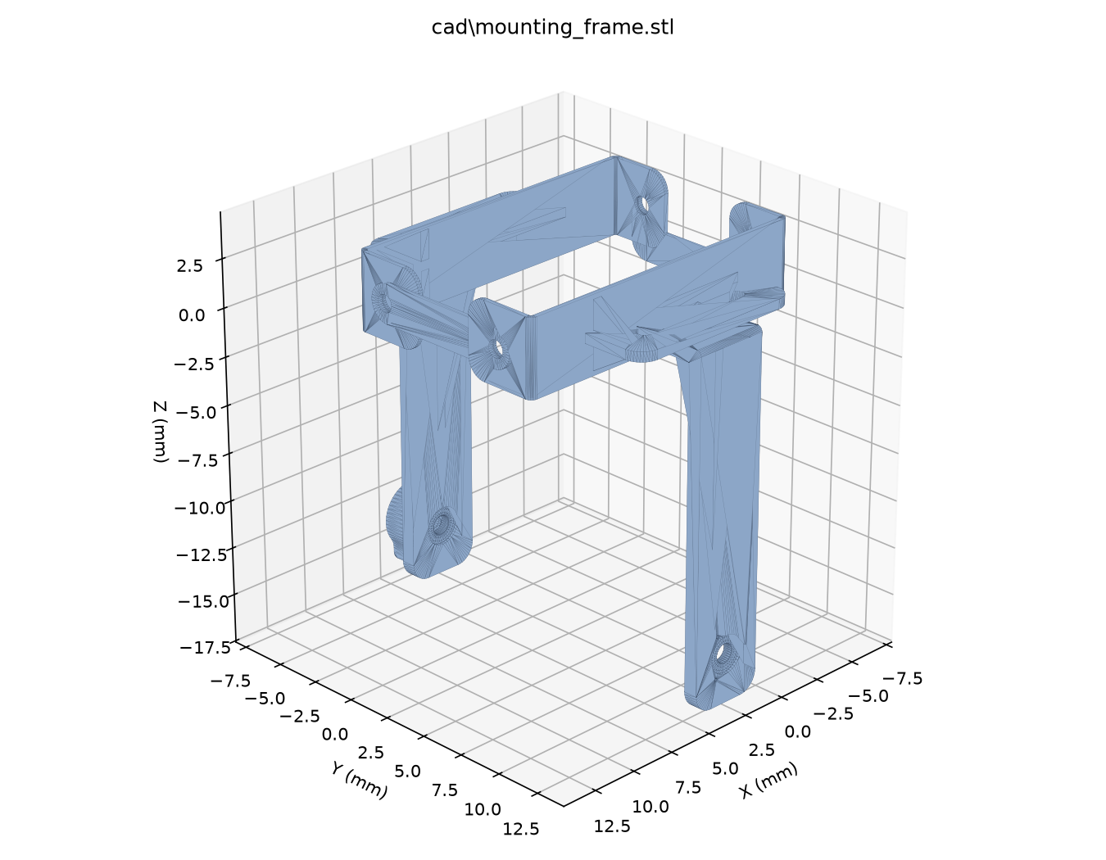
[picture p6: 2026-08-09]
renders/real_mounting_frame.png

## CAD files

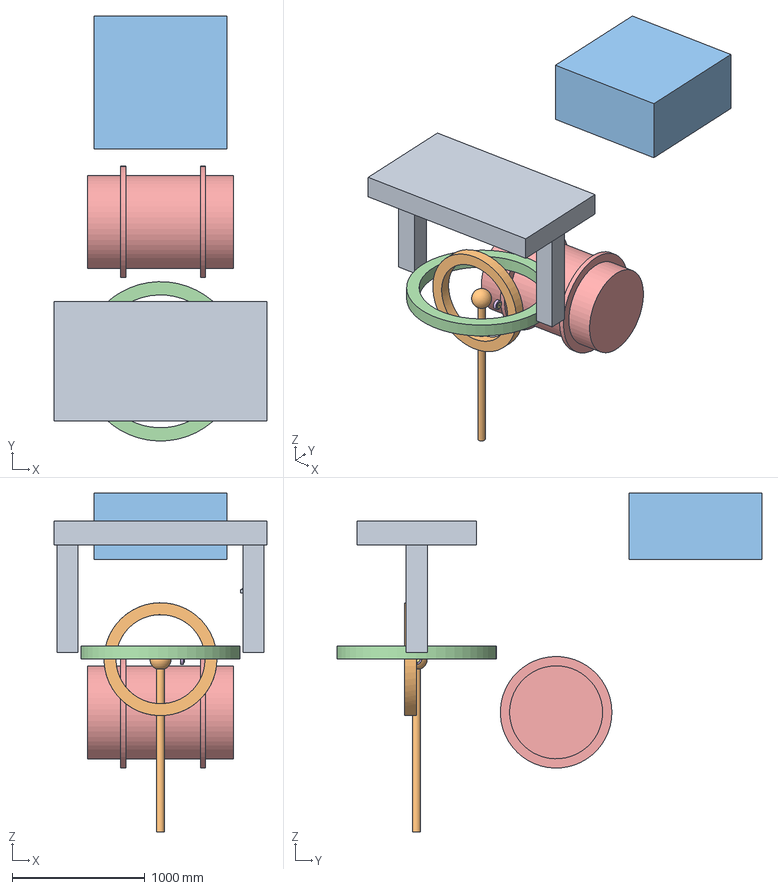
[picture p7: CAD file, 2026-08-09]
step/gimbal_assembly.step
1600.0 x 3199.7 x 2550.0 mm

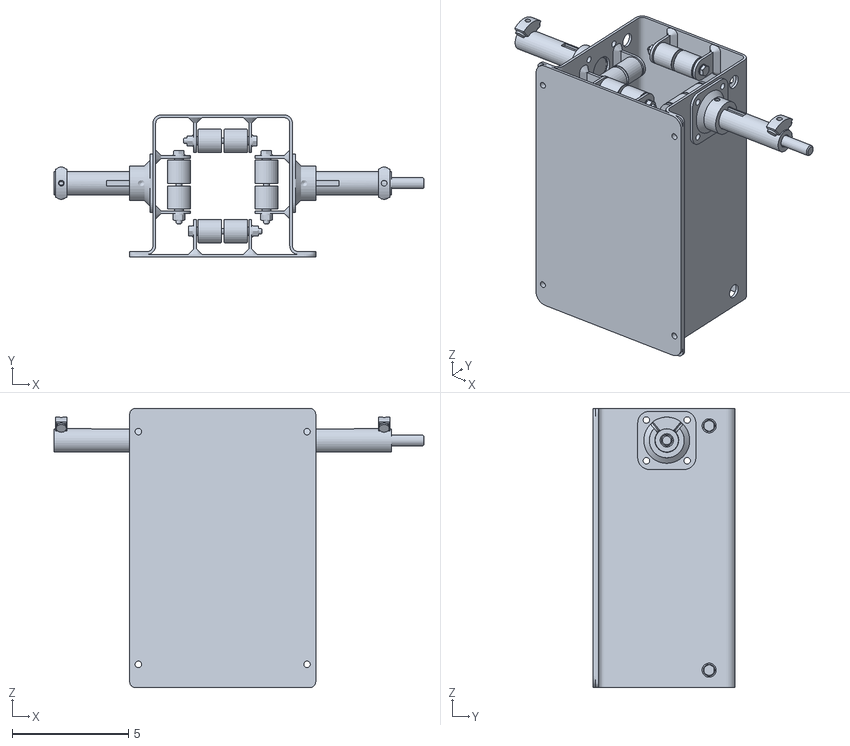
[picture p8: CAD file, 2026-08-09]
cad/inner_yoke.stl
15.9 x 6.12 x 12.0

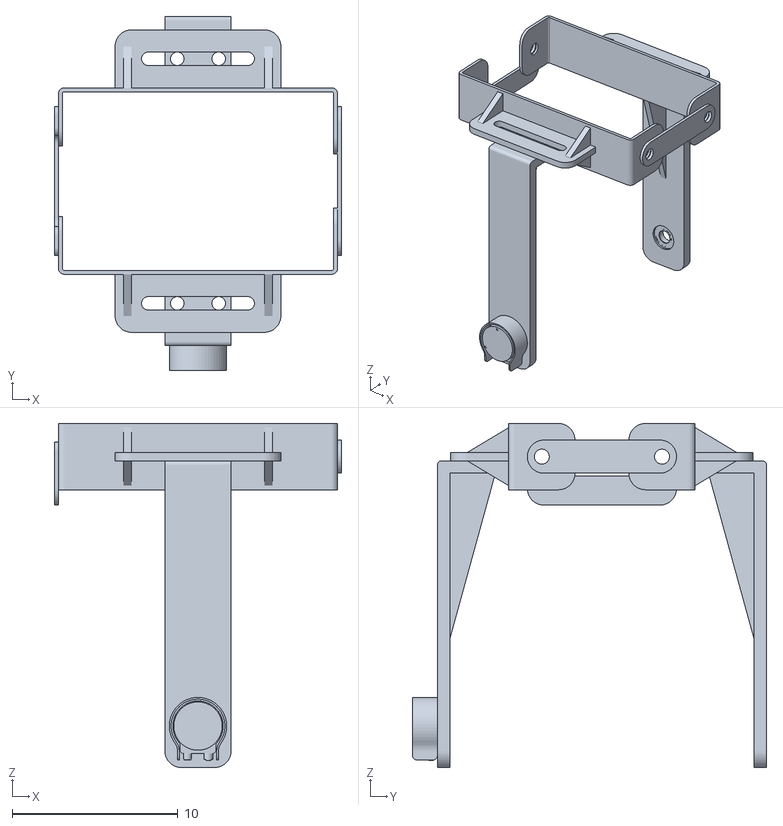
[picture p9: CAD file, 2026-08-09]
cad/mounting_frame.stl
17.3 x 21.3 x 20.8

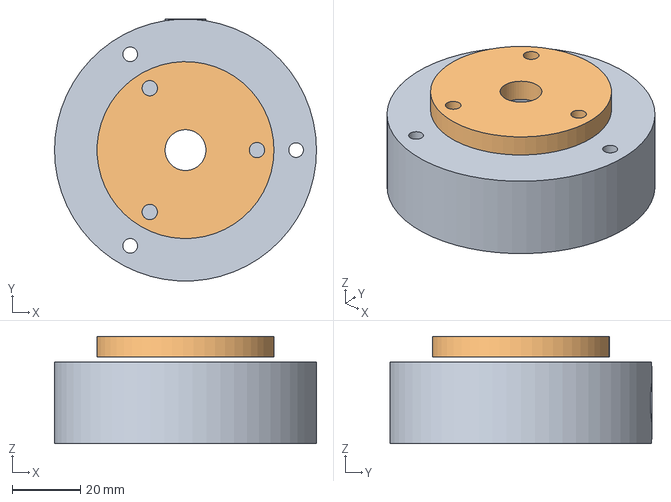
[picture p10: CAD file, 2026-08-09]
step/qr24_encoder_pair.step
77.0 x 76.9 x 31.5 mm

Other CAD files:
stl/gimbal_assembly.stl
stl/qr24_encoder_pair.stl

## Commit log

2026-08-09 Initial commit: InReel deflection system CAD, docs, and simulator
    Mechanical CAD (real yoke/frame STLs + placeholder CadQuery assembly),
    the interactive gimbal axis simulator, reel-inertia model, and
    supporting derivation/verification scripts.
    [gimbal_assembly.step, gimbal_assembly.stl, inner_yoke.stl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]
2026-08-09 Replace inner_yoke.stl with Concept 2 design
    New part has its own native coordinate frame with no exact CAD pivot
    coordinates available, unlike every other part in this repo. Derived
    INNER_YOKE_NATIVE_OFFSET and CABLE_EXIT_OFFSET from the raw STL mesh
    (circle-fit the stub shaft axes, found the tube's hollow bottom-face
    centroid) rather than a CAD-tool readout, and flagged the resulting
    stub-to-hole span as an estimate pending exact coordinates.
    Verified via scripts/render_combined.py and live in the browser: the
    part sits centered and connected inside outer_yoke's ring, right-side
    up, with both sliders still driving it correctly.
    [inner_yoke.stl]
2026-08-09 Cache-bust cad/*.stl fetches to prevent stale-mesh bugs
    Python's http.server sends no cache-control headers, so a browser can
    keep serving an old cached STL after the file on disk is replaced,
    even across a hard reload of the page -- since the sub-resource URL
    never changed. Surfaced by the inner_yoke.stl swap: a user saw the old
    mesh rendered with the new part's transform numbers, floating
    disconnected outside the assembly. Appending a version query to each
    STL URL forces a fresh fetch whenever CAD_ASSET_VERSION is bumped.
2026-08-09 Replace outer_yoke.stl with Concept 2 design
    More consequential than the inner_yoke swap: NATIVE_PIVOT has always
    been outer_yoke's own native coordinates, so this means re-deriving
    the shared pivot from scratch (mesh-derived, same as inner_yoke --
    no exact CAD coordinates available), then recomputing
    FRAME_NATIVE_OFFSET and INNER_YOKE_NATIVE_OFFSET against the new value.
    Flagged open question: axis-1 is asymmetric on the new part (left =
    confirmed-hollow bore, right = confirmed-solid pin), unlike the old
    symmetric two-hole design. The new inner_yoke has male stubs on both
    ends, so the right side doesn't have an obvious valid mate as modeled.
    Averaged both ends for visualization; doesn't re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
2026-08-09 Add demo scenarios panel: gimbal pull test cases
    Five one-click presets (worst-case hard stops on X, extremes on Y in
    both directions, and a combined pull) so a demo can jump straight to
    a known deflection instead of hand-dialing sliders. Each button turns
    off tension-driven Y first, since tension can only produce positive
    (away-from-rig) Y and one scenario needs negative. The matching
    button highlights live whenever the sliders exactly match a preset.
2026-08-09 Add Obstacle Snag demo scenario: full sensor-to-actuator chain
    Scripted multi-phase deflection timeline (neutral -> fast catch on
    both axes -> held with organic jitter while a tension proxy ramps ->
    fast release with overshoot -> settle) that drives a0Deg/a1Deg the
    same way the five instant-preset buttons do, one frame at a time, so
    it exercises the real computeAxis() deadzone math, the sliders' native
    min/max hard stop, and the actual EMA/ramp-lagged reel-trim controller
    -- nothing here is a parallel calculation.
    Adds a simple procedural obstacle (jagged icosahedron, no CAD import)
    along the cable path between the gimbal and reel barrel, color-keyed
    to the scenario's live phase. New readou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
2026-08-09 Add sagging supply cable from gimbal to a fixed power-supply anchor
    New placeholder pole+anchor mesh (no CAD import) opposite the obstacle,
    away from the rig/barrel so the cable run reads clearly. Each frame,
    a tube mesh is drawn from the gimbal's real cable-exit point (hub's
    live world position, reflecting current deflection from any source --
    sliders, presets, drag, or the Obstacle Snag scenario) to the fixed
    anchor, sagging via a standard shallow-sag parabolic approximation of
    a catenary. Slack is driven directly by the drum inertia model's live
    payoutLength: fully spooled pulls it taut (zero sag), more paid-out
    cable visibly droops more.
    The tube's BufferGeometry is built once (buildTub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
2026-08-09 Tie the supply cable/power supply into the Obstacle Snag scenario
    Two power-supply base positions instead of one: NORMAL (pure -Y, away
    from the rig, the resting scene) and SNAG (+X/-Y quadrant, roughly in
    line with the gimbal->obstacle direction). updateHangingCable() now
    switches between them every frame based on the scenario's live phase
    -- a "scene switch" bracketing the whole run (NEUTRAL through SETTLE),
    not just the catch moment.
    Added cableWrapFactor (0-1), set per-phase in updateObstacleScenario:
    ramps up through CATCH, holds at 1 through HOLD, eases back to 0
    through RELEASE. Blends the cable's routing midpoint toward a point
    just above the obstacle, solved so the quadratic-bezier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
2026-08-09 Hide the old straight cable during the Obstacle Snag scenario
    The short white cylinder never showed tension -- always perfectly
    straight regardless of payout. Hidden for the scenario's duration
    (NEUTRAL through SETTLE) so the sagging supply cable, which DOES
    represent real tension/slack via the drum model, is the only thing
    reading as "the cable connected to the gimbal" while that story is
    being told. Reappears automatically once the scenario returns to
    IDLE. hub (the exit-point marker) stays visible per explicit choice.
    Verified with two full real-time-paced NEUTRAL->...->IDLE runs, zero
    console errors both times.
2026-08-10 Add live control logic diagram panel
    Toggleable SVG overlay (plain DOM, not a Three.js object) showing the
    reference signal chain: Deflection Measurement Device -> Deflection
    System Computer -> Tension Control Computer -> Cable Reel Motor
    Controller -> Cable Reel Motor, with Velocity Data and Cable Length
    Data feeding back the other way.
    Every readout is pulled directly from existing state -- a0Deg/a1Deg
    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
2026-08-10 Extend the cable into a continuous gimbal-to-barrel spiral wind
    The tube now runs as one continuous THREE.CurvePath: power supply
    anchor -> gimbal exit (existing sag segment, reversed to fit this
    order) -> mounting anchor (new fixed cable-guide point near the
    barrel) -> a single-layer helix wound onto the barrel surface. All
    four sub-curves feed the same buildTubeGeometry()/updateTubeFromCurve()
    infrastructure already used for the sag segment -- one BufferGeometry,
    rewritten in place every frame, never reallocated.
    New BarrelHelixCurve (extends THREE.Curve) generates the wound portion
    analytically: pitch derives from CABLE_OD_M (already 2.12in / the
    Nexans spec used elsewhere in this file)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
2026-08-10 Add Rig Motion Demo: tracked chassis tram/point-turn drives deflection from geometry
    Parents frame/gimbal/mounting-guide/barrel under a new movable rigGroup,
    separate from the fixed power-supply anchor, so the whole assembly can be
    driven as one rigid body. Adds a two-track differential-drive kinematic
    model (equal same-sign speeds -> straight tram, equal-opposite -> a near
    zero radius point turn) with both a scripted demo sequence (forward, pause,
    back, turn left, pause, turn right) and live WASD/arrow-key manual drive,
    sharing the same leftTrackSpeed/rightTrackSpeed state either way.
    While either drive mode is active, gimbal deflection is no longer read from
    the presets/sliders/drag or th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
2026-08-10 Add 2x2 Drill Pattern demo: waypoint nav built on the Rig Motion model
    Adds a fourth scripted preset that drives the rig through four hole
    locations in a 2x2 grid (HOLE_SPACING constant, serpentine order so every
    leg is a short adjacent hop rather than a diagonal crossing) and lowers/
    raises a decorative drill bit at each stop.
    Deliberately does NOT introduce a new movement or deflection system:
    - Navigation reuses the exact same leftTrackSpeed/rightTrackSpeed model,
    MAX_TRACK_SPEED, and the same asymmetric 0.97 point-turn pair the Rig
    Motion Demo's TURN_LEFT/TURN_RIGHT phases already use -- the only new
    logic is a closed-loop trigger (turn until heading error < ~1.1 degrees,
    then t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
2026-08-10 Move the 2x2 Drill Pattern grid to the +Y side, away from the power supply
    HOLE_GRID_CENTER was (1.3, 0, 0.2), which straddled toward the supply's
    side of the origin (supply anchor sits at Z=-1.4). Moved to (1.3, 0, 2.2)
    so the whole grid sits on Z>0 -- the same "+Y, away from the rig" side the
    rig's own pulled-back start position (Z=1.5) already occupies, and clearly
    separated from the supply anchor's side rather than mixed with it.
    Reordered DRILL_HOLES to start from the corner nearest the rig's start
    position again (now the smaller-Z corner, since the grid flipped sides),
    keeping the same serpentine/adjacent-hop property. Re-fit the "2x2 Drill
    Pattern" camera preset's target and radius t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
2026-08-10 Give the rendered cable a visible response to tension and reel motion
    Adds a canonical cableTensionPct (0-100, smoothed) computed once per frame
    in stepReelTrim() -- base = deflection magnitude (currentVX/currentVY,
    already fused from whichever input is driving the gimbal: sliders, drag,
    presets, Obstacle Snag's own scripted deflection, Rig Motion, the Drill
    Pattern demo) plus a smaller drum-speed contribution, with the Obstacle
    Snag scenario's existing snagTensionPct spike layered additively on top
    rather than replacing it. Wired into the one place everything already
    shares (updateHangingCable/updateControlDiagram), so no scenario needed
    its own copy -- replaces the control logic diagram's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
2026-08-10 Deepen the hanging cable's sag, with a ground-clearance safeguard
    Raised SUPPLY_CABLE_SLACK_PER_PAYOUT (0.1->0.18) and SUPPLY_CABLE_MAX_SAG
    (0.6->0.7) so the same payout produces a visibly deeper droop. The sag-vs-
    slack relationship is a square root, so the old slack factor needed a lot
    of payout before the droop read as more than subtle, and the old cap was
    already the binding constraint at realistic payout/low-tension
    combinations -- raising slack alone wouldn't have shown much without also
    raising the ceiling it was hitting.
    (Discussed unreeling faster via a higher duty cycle as the alternative --
    duty only controls how fast the drum gets there, not how much slack exists
    at a given payo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
2026-08-10 Add Capacity Interlock Stress demo: deplete, trip, hold, restore, rearm
    New scripted preset (fifth alongside Obstacle Snag, Rig Motion, Drill
    Pattern) that trams away from the power supply until the REAL capacity
    interlock (trammingBlocked, driven by turnsRemaining/capacityPct further
    down in stepReelTrim) actually trips -- not a fixed duration -- holds so
    TRAM BLOCKED is clearly visible, then restores and rearms. Reuses the exact
    same track-speed/kinematic model and geometry-derived deflection every
    other rig-motion demo already drives; the only new logic is the trigger
    condition (waiting on the real interlock state) and the preload/cleanup
    around it. Extends setScenarioControlsEnabled and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
2026-08-10 Add a timeline strip chart for tension/duty/deflection to the control diagram
    Adds a scrolling Canvas 2D line chart (last 20s) beneath the existing
    control logic diagram, plotting the same three values its live readouts
    already show -- tension, duty cycle, and deflection magnitude -- so
    cause-and-effect (a deflection spike driving a duty ramp driving a tension
    rise) reads as a shape over time instead of only as numbers changing frame
    to frame.
    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
2026-08-10 Add a Guided Tour that runs all four scripted demos back to back
    New "Guided tour" panel, first thing visible when Demo scenarios opens --
    one button runs Obstacle Snag, Rig Motion, the 2x2 Drill Pattern, and the
    Capacity Interlock Stress demo in sequence, each with a short caption
    explaining what to watch for, so the sim can be handed to someone
    unfamiliar with it without them needing to know where to click first.
    Implemented as a meta-sequencer, not a fifth demo: it owns no track speed
    or deflection state of its own. TOUR_STEPS just pairs each existing demo's
    own trigger (obstacleSnagBtn.click(), etc.) with its own completion signal
    (snagPhase === 'IDLE', etc.) -- the tour only ever click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
2026-08-10 Add Combined Route Demo: waypoint nav + obstacle snag + drill, one leg
    New scripted preset (last of the six) that drives to a drill hole placed
    on the far side of the shared obstacle from the rig's start, so the
    straight-line route naturally passes within ROUTE_OBSTACLE_TRIGGER_DIST
    (0.4 units) of it -- no pathfinding or collision geometry, just picking a
    destination that makes the existing waypoint math produce a route that
    goes near the obstacle. When the rig gets that close mid-transit, it stops
    and triggers the real Obstacle Snag scenario in place (same
    obstacleSnagBtn.click(), waited on via snagPhase, exactly how the Guided
    Tour already nests it); once that finishes, it resumes the same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
2026-08-10 Add capacity-demo threshold notifications, and a pinned live dashboard
    Two pieces of UI work landed together in this pass:
    1. Capacity Interlock Stress demo now shows its own warn/block/rearm
    thresholds (previously only block/rearm) plus a narrated "interlock
    response" line mirroring the real Tramming interlock panel's own verdict
    text (mirrored, not duplicated logic -- same blocked/warn formula, since
    this reads a frame ahead of where stepReelTrim's own capacity block
    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
